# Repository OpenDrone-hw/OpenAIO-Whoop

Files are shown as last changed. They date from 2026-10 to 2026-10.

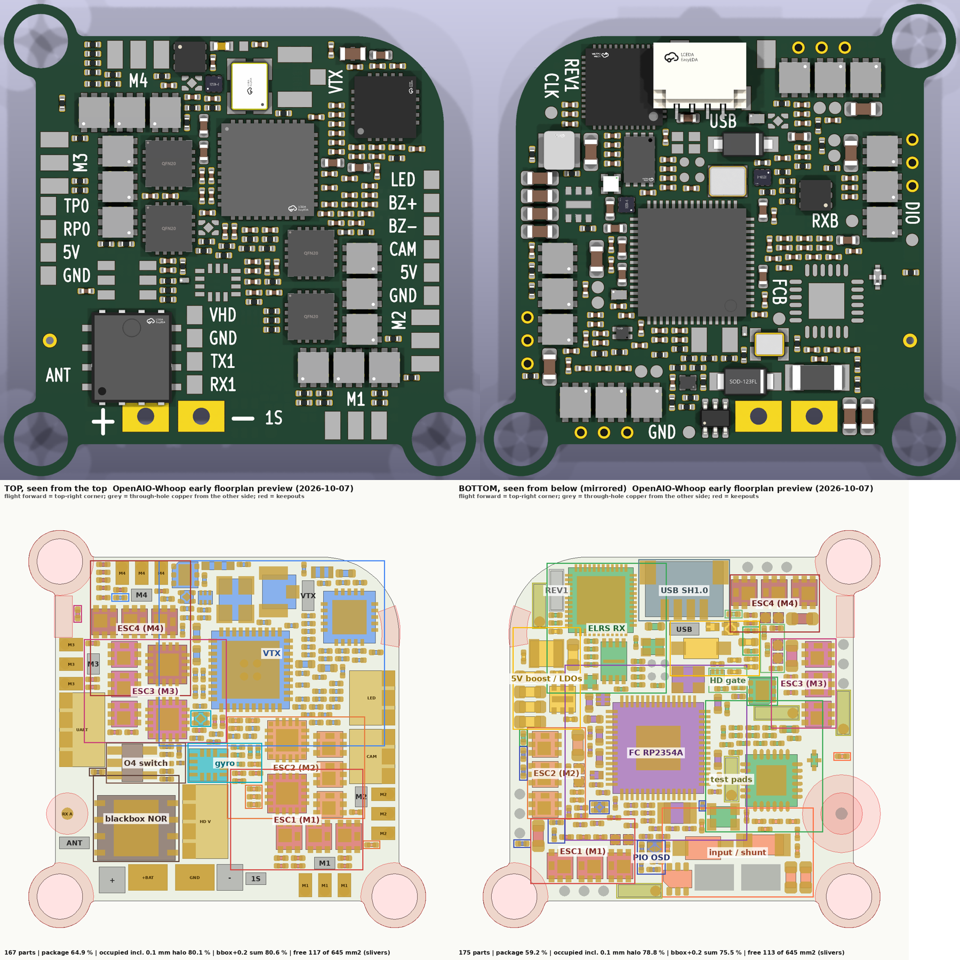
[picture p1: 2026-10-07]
images/floorplan-preview-overview.png

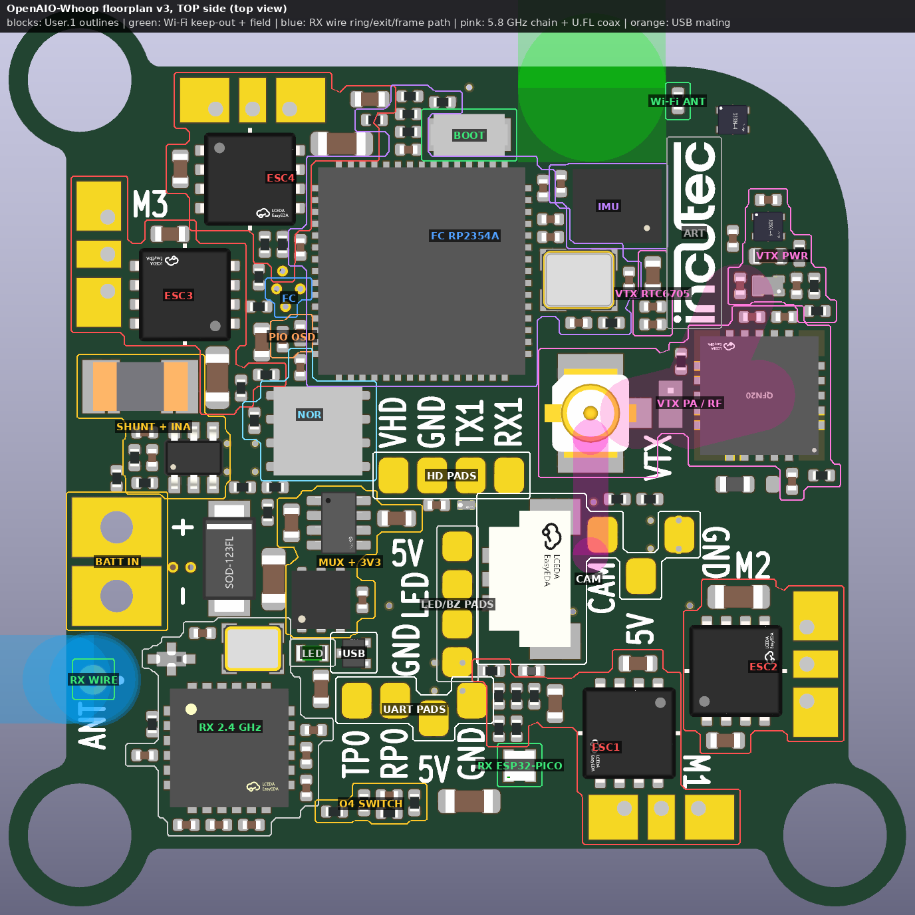
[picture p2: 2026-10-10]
images/floorplan-top.png

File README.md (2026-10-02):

# OpenAIO-Whoop

An all-in-one board for 1S whoops, 65 to 85 mm class: flight controller, four
brushless ESC channels, an ExpressLRS receiver and an onboard analog VTX on a
25.5 x 25.5 mm board. The 1S sibling of
[OpenAIO](https://github.com/OpenDrone-hw/OpenAIO), which covers 2S to 6S on
the same mounting pattern.




## Why

Whoops are where an AIO is not a convenience but the only option: there is no
room for a stack and no weight budget for connectors. 2S and up is OpenAIO's
range, so what is left for a second board is 1S, where the power tree starts
from a single cell and everything below +5V has to be boosted rather than
bucked. That is the whole design problem, and it is worth solving once.

Analog is the reason this board is separate rather than a variant. A 1S whoop
is the last class still flying analog in volume, and an onboard VTX is what
makes the board worth building instead of pointing people at a digital AIO
with an HD port.

## VTX dependency

RTC6705 is listed on LCSC (C913074) with no stock (checked 2026-10-02), so an
onboard analog VTX cannot be assembled from LCSC-sourced parts today; see
[OpenVTX](https://github.com/OpenDrone-hw/OpenVTX) for the same constraint. This board waits on that part becoming
orderable, or on a sourceable equivalent. Nothing else about it is hard, and
nothing has been drawn.

## Specifications

Targets. The board does not exist yet.

| | |
|---|---|
| Target class | 1S whoops, 65 to 85 mm |
| Mounting | 25.5 x 25.5 mm |
| Input | 1S LiPo |
| Flight controller | RP2354A class, Betaflight target |
| ESC | 4 channels |
| Receiver | ExpressLRS 2.4 GHz, serial |
| Video | Onboard analog VTX and OSD |
| Blackbox | SPI NOR flash |
| Assembly | Chosen per release. LCSC basic parts preferred |

## Constraints

- 25.5 x 25.5 mm mounting pattern, shared with OpenAIO.
- 1S only. 2S and above is OpenAIO, and covering both here would mean a wider
  front end for a range another board already serves.
- FC section reuses the [OpenFC-Lite-Mini](https://github.com/OpenDrone-hw/OpenFC-Lite-Mini) RP2354A design; Betaflight target derived from its target.
- Receiver is serial ELRS 2.4 GHz, reusing the [OpenRX Lite](https://github.com/OpenDrone-hw/OpenRX-Lite) design.
- Assembly from LCSC parts, basic parts preferred; assembly house chosen per
  release. Fab-ready manufacturing files are kept in a private Incutec production repository and are not published.

## Prior art

- [OpenFC-Lite-Mini](https://github.com/OpenDrone-hw/OpenFC-Lite-Mini) and [OpenRX Lite](https://github.com/OpenDrone-hw/OpenRX-Lite): the FC and RX stages this board reuses.
- [OpenAIO](https://github.com/OpenDrone-hw/OpenAIO): the 2-6S board, and the source of the ESC and power sheets that do not survive the drop to one cell.
- The class reference is the BetaFPV Matrix 1S 5IN1 II.
- An earlier stitched design was reset in August 2026 (see the git history before #9); reference for the thinking, not a design to continue from.

## Design questions

Open questions for the design:

- **VTX part.** Is there an RTC6705 equivalent in stock on LCSC, or a
  different route to 25 mW to 200 mW on the 5.8 GHz band that JLCPCB can place?
- **Power stage.** At 1S the pack is 3.0 to 4.35 V. Driven half-bridge needs a
  boosted gate rail; direct-drive P+N needs no driver but costs dead time,
  which AM32's `USE_INVERTED_HIGH` F421 targets run at 120-140 against 22-75
  for driver-based targets. Which one, and what does it do to the copper?
- **Electronics rail.** Everything from +5V down has to come from a boost or
  buck-boost off one cell, and it has to hold up with the cell sagging under
  full throttle. That is the part existing 1S-2S AIOs get wrong.
- **Motor connection.** Solder pads or connectors, given the class usually
  means replaceable motors.
- **Antenna.** Where the RX antenna and the VTX antenna go on a board this
  size with a duct around it, without desensitising the receiver.

## In the line

What pairs with what, and what is available:
[opendrone.be](https://opendrone.be).

## Contributing

See [CONTRIBUTING.md](CONTRIBUTING.md). KiCad files cannot be merged, so say
what you intend to change before you do, on
[Discord](https://discord.gg/v3sWmTcx3R).

## License

Hardware licensed under [CERN-OHL-S-2.0](https://ohwr.org/cern_ohl_s_v2.txt),
see [LICENSE](LICENSE).

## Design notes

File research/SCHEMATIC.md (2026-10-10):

# OpenAIO-Whoop schematic (P4 integration, 2026-10-09)

Status: the eleven sheet files written by the P4 shards are merged into one hierarchy and pass every scripted
check. P4 critique round 1 (4 MAJOR, 22 MINOR: 25 fixed, 1 rejected), round 2 (2 MAJOR, 19 MINOR: 19 fixed,
2 fixed in part, 0 rejected), round 3 (2 MAJOR, 17 MINOR: 17 fixed, 2 fixed in part, 0 rejected) and round 4
(7 MAJOR, 12 MINOR, two pairs of duplicates: 19 fixed, 0 rejected; section "P4 critique round 4") are applied;
the loop (D22: no BLOCKER / MAJOR left) continues with round 5. The board was **not** synced; round 4 changed
only its silkscreen again (the routing prep had promoted a checkpoint without the round-3 LED-row / M4 labels).
A scratch sync of the round-4 schematic gives schematic parity **0** (repo board: 25 until the next sync). The
P5 placement conditions are scripted (`hardware/tools/check_p5_conditions.py`, round 4 adds the RTC6705 C103
bypass and C94 / C95 crystal loads) and fail 31 of 46 on the current board (open item 10).

| Check | Result |
|---|---|
| `kicad-cli sch erc` (all severities) | **0 errors, 2 warnings** (both justified below); baseline before integration: 2 errors, 105 warnings |
| `hardware/tools/check_netlist.py` | **7 ok, 0 FAIL** (N1-N6, N5 run for the FC and the RX; N6 now also checks each net's class through the .kicad_pro patterns, D82) |
| `hardware/tools/check_conventions.py` | **39 ok, 0 FAIL**, 4 warn, 3 skip after round 4 (B7 requires each solder pad's nearest aligned silk label to equal its pad code; B8 / B9 pass on the board labels). Correction: round 3 reported 39 / 0, but the routing prep promoted `route/ckpt/28_candidate` over the board at 03:03:28, 6 s after the re-apply, so the repo board read **37 ok, 2 FAIL (B7, B9)** until round 4 re-applied the labels with `hardware/tools/silk_pad_labels.py` |
| `sch_visual_check.py` (commons, KiCad 10 hide fix: `p2v3/p4/rx/tools/svc_k10.py`, round 4 adds `textbox_intrusion`: a text or symbol body inside a note's rectangle, which caught C82's '+3V3' under the RX MCU note: 5 hits on the round-3 sheets) | **0 hits on all 11 sheets**; the unpatched commons copy counts the KiCad 10 hidden fields (9251 → 9353, not meaningful, ruling 2026-10-09); it has no frame-to-frame check, so round 2 added `frame_check.py` and round 3 (`p2v3/p4/fix3/scripts/frame_check.py`) gave it a title-block test: **0 title-block hits on all 11 sheets** (was 1: ESC half-bridge frame); its 19 other hits are house-style items present in the sibling sheets (OSD hand-drawn table grid, notes outside frames on RP2350A / ESC / PADS) |
| `hardware/tools/check_p5_conditions.py` (board placement conditions) | 15 ok, **31 FAIL** on the current board (round 3 added SMPS, BOOT, USB series R, NOR cap and LP5907 CIN conditions; round 4 adds C103 at RTC6705 pins 31/32 same side <= 1.0 mm (3.3 mm, F vs B), C94 / C95 at pins 24 / 25 <= 1.5 mm (2.0 / 4.5 mm)): P5 input, not a schematic error (open item 10) |
| `kicad-cli pcb drc --schematic-parity` | repo board **25** (21 footprint_filters_mismatch from the schematic, now fixed by project-lib copies, + 4 pending the C122 / D1 sync); after a scratch `sync_pcb.py` of the round-4 schematic **0** (ptest in `p2v3/p4/fix4`); the U20 NU / GND shorting_items error clears with that sync, the U5 WSON and C122 0402 lands then need 3 vias moved (FLOORPLAN open item 13) |
| `hardware/tools/check_footprint.py` R_0402_Selector_3Pad | PASS, 0 WARN (pad 3 paste-free by spec) |
| bom_plan parity (refs, values, footprints, symbols, MPN, Manufacturer, LCSC, DNP, BOM flag) | 274 of 274 symbols equal (check_netlist N4); LOGO1 is a board-only footprint |
| Netlist | 271 board parts (H1-H3 are schematic-only); 236 BOM placements, 82 BOM lines; 72 no-connect pins (U20 NU now on GND), 0 auto-named nets |
| Board silk (rounds 3 and 4) | kicad-cli DRC on the board: +1 silk_overlap warning (J33 GND label 0.148 mm from U6's tented EP via ring, accepted), no other change; round 4 re-applied the labels to the repo board and 21 route checkpoints / saves (`hardware/tools/silk_pad_labels.py`, `--check` = the promote gate) |

PDF: `hardware/OpenAIO-Whoop-schematic.pdf` (14 pages).

## Sheets

| Page | Sheet (file) | Paper | Refs | Reused from | Generator (scratchpad `p2v3/p4/`) |
|---|---|---|---|---|---|
| 1 | Root (`OpenAIO-Whoop.kicad_sch`) | A3 | - | OpenAIO root layout, signal flow left to right; power table | `hardware/tools/sch_root.py` from `sch_contract.json` |
| 2 | POWER (`power.kicad_sch`) | A3 | 38 | OpenFC-Lite-Mini power (LP5912 block), OpenAIO battery shunt + INA186; TPS61022, SGM40661, TPS2116, TPS22810 from TI/SGMICRO datasheets | `integrate/gens/power_sheet.py` |
| 3-6 | ESC1-ESC4 (`esc_channel.kicad_sch`, one file x4) | A4 | 17 x4 | OpenAIO esc_channel (BEMF network, C2 test points); EFM8BB51 + AGM210MAP stage new (D56) | `esc/build_esc.py` |
| 7 | RP2350A (`rp2350a.kicad_sch`) | A2 | 34 | OpenFC-Lite-Mini rp2350a (core, crystal, SMPS, USB series, VBAT divider, beeper FET) | `integrate/gens/build_rp2350a.py` |
| 8 | IMU (`imu.kicad_sch`) | A5 | 5 | OpenFC-Lite-Mini imu; commons blocks LDO_IMU_TPS7A2033 / IMU_ICM42688P_SPI | `imu/build_imu.py` |
| 9 | BLACKBOX (`blackbox.kicad_sch`) | A5 | 3 | OpenFC-Lite-Mini blackbox frame + SPI0 interface; PY25Q128HA NOR (D66) | `blackbox/build_blackbox.py` |
| 10 | OSD (`osd.kicad_sch`) | A4 | 12 | OpenFC-Lite-Mini osd (SN74LVC1G3157 + TLV7031 + SDM02U30), levels scaled (P4-10) | `osd/build_osd.py` |
| 11 | RX (`rx_esp32_sx1281.kicad_sch`) | A3 | 25 | OpenRX-Lite-UFL (SX1281 LDO mode, 52 MHz TCXO, Wi-Fi chip-antenna pi match, WS2812), ESP32-PICO-V3 DS Fig. 11 | `rx/build_rx.py` |
| 12 | VTX (`vtx.kicad_sch`) | A2 | 58 | OpenOSD-X v1.01 reference (video network, loop filter, PAOUT1 feed), Skyworks SE5004L EK1; no sibling sheet exists | `integrate/gens/gen_vtx.py` |
| 13 | LED (`led.kicad_sch`) | A5 | 4 | OpenFC-Lite-Mini rp2350a status-LED block (sink drive) | `integrate/gens/build_led.py` |
| 14 | PADS (`pads.kicad_sch`) | A3 | 27 | OpenFC-Lite-Mini pads (Conn_01x01 groups), OpenFC-Lite JST SH plug frame; camera plug, motor lands, ESD array new | `integrate/gens/build_pads.py` |

Naming (round 3): the sheet name **RP2350A**, its file `rp2350a.kicad_sch`, the net paths `/RP2350A/*` and the
bom_plan `sheet` field `rp2350a` (component class RP2350A) all follow the house OpenFC-Lite-Mini sheet (the RP2350
family name, as every other bom_plan sheet field follows its file); the part and the sheet title are RP2354A.

`integrate/gens/*` are the shard generators patched for the integration (`integrate/scripts/patch_gens.py` applies
the edits to the shard originals). After any generator run, `hardware/tools/sch_integrate.py` must run once.

## What the integration changed

- **Library pin types.** Twelve OpenDrone catalogue symbols typed every pin `unspecified`, which caused 105 ERC
  warnings and both errors (U13 SCLK and AE1 not driven). Per the ruling they are now project copies in
  `lib.kicad_sym` with datasheet pin types (list in research/LIBRARY.md); `bom_plan.json` `symbol` points at the
  copies. Pin-name cosmetics fixed on the copies: INA186, AP1606, SDM02U30, SDM02M30 (D8) names hidden, AOTA numbers
  hidden, BMI270 pins 2/3 lengthened so they reach the body.
- **PWR_FLAGs.** Regulator outputs are now `power_out` pins, so the flags on +3V3 (POWER) and +3V3_VTX (VTX) were
  removed (a flag next to a power output is an ERC error). Flags stay where the only source is passive or a
  connector: +BATT_IN, GND, +BATT, +5V_CAM, VBUS, +1V1, PA_VCC, plus a new one on VREG_AVDD (R41 RC filter, ERC asked).
  Contract rule 7 updated.
- **Rulings applied.** R84 10k -> 1k (RC0201FR-071KL; LP5912 EN 0.03-0.04 V with GPIO21 low). New **C134** 4.7 uF
  (CL05A475MP5NRNC, same line as C56) on +1V1 at DVDD pin 23. Net class pattern `*ADC_CURR*` -> Analog and `/VBUS` ->
  Power (setup_board.py NETCLASS_PATTERNS and .kicad_pro, same order). bom_plan net notes synced to the netlist for
  35 parts (U1 / C5 on SHUNT_SENSE_P_RC / N_RC, R64 on RTC_VT, R59 shunt, U22 from +3V3_VTX, O4_EN = U5_EN, ...).
  +3V3 Wi-Fi peak (0.48 A, bench-only mode) in the root power table.
- **Local labels on every multi-pin net** (contract rule 8): the 19 auto-named nets now carry labels named after the
  driving pin or the contract name: VTX RTC_CP / RTC_VT / RTC_LF, VT_MOD / VT_MOD_N1 / VT_MOD_N2, U19_XTAL1 / XTAL2,
  U19_REG1D8, U19_SPILE / SPICLK / SPIDATA, PA_RC1, Q27_B, Q27_E; RP2350A VREG_LX; POWER U5_CT; LED D5_K, D6_K.
- **Fields.** LCSC made consistent per MPN (GRM033C81E104KE14D = C181047, GRM155C80J106ME11D = C237279, sources in
  BOM-REDUCTION.md), so C12 / C15 and the other parts of those lines carry it.
- **Power-symbol references** numbered once over the hierarchy (#PWR01-#PWR247, #FLG01-#FLG08); the shards used
  colliding per-shard ranges.
- **Contract text** (sch_contract.json): J31 pinout (1 GND, 2 D-, 3 D+, 4 VBUS), USB block and PADS sheet source
  attribution, IMU pins 2/3/10/11 NC, R84, C134, VTX net names, PWR_FLAG rule, A9 decided, VBUS / ADC_CURR patterns.
- **A9 (LCSC) decided.** check_conventions A9 requires MPN + Manufacturer and an LCSC field; the LCSC value is
  required where the part has one (D60, NextPCB sources by MPN) and check_netlist N3 compares it to bom_plan. 63 BOM
  placements (25 lines) have no LCSC number. LINEUP-CONVENTIONS rule 9 carries the note.
- **Docs synced.** PINMAP §2/§3/§6 net columns use the schematic names (underscore buses, pin-side nets
  U10_USB_DM/DP, QSPI_SS, ADC_CURR, VTX_PWR_CTL, Wi-Fi AE2 row, GPIO0 button row) and list every ESP32 pin;
  DESIGN-SPEC R84 1 kOhm, IMU pins 2/3 NC, Wi-Fi paragraph marked superseded by D58. PADS sheet note follows D76
  (vertical BM04B), not the withdrawn D72 side-entry plug.
- **Tools.** New `hardware/tools/sch_integrate.py` (project-wide lib refresh, field sync, power references) and
  `hardware/tools/check_netlist.py`. `sch_build.py` no longer copies stock `property private` entries (kicad-cli
  refused those files); `sch_root.py` gives the power table a deterministic uuid.

## P4 critique round 1 (2026-10-09)

Single-writer fix pass `p2v3/p4/fix1` (scripts there; decisions D77-D80). Each item was checked against the
datasheet or file first.

| # | Sev | Item | Verdict | What changed |
|---|---|---|---|---|
| 1 | MAJOR | ESC commutation loop closed through planes (one shared 22 µF per ESC) | fixed (D77) | one 10 µF X6S 0402 GRM155C80J106ME11D per AGM210MAP, pin 3 S2 to pin 1 S1 at the lead side, via-in-pad: C20 / C23 / C21 per ESC (x4); 22 µF 0603 cell bulk out; ESC sheet note, bom_plan, DESIGN-SPEC §4.3 corrected |
| 2 | MAJOR | X1 ESR 150 Ω vs RP2350 Table 629 50 Ω | fixed (D78) | Abracon ABM8-272-T3 (C20625731, 3225 Dense land), C42 / C43 15 pF and R40 1k kept |
| 3 | MAJOR | FL1 TDK DEA 50 Ω LPF without the Semtech match / DC block | fixed (D80) | Johanson 2450FM07D0034T (house part, matched + DC blocked), lib:2450FM07D0034T + lib:FILTER-SMD_4P-L1.0-W0.5-L_W, IN at RFIO |
| 4 | MAJOR | R67 selector anchor on pad 2 (CPL centres the 0402 between lands) | fixed | footprint origin at the pad 1-2 midpoint, land spec updated, check_footprint PASS |
| 5 | MINOR | DESIGN-SPEC / PINMAP not synced to D56 / D57 | fixed | spec P4-status block, §1, §3, §4.1-4.3, §4.10, §15; PINMAP §7.1 / §7.3 |
| 6 | MINOR | root +5V row shows the HD figure of +5V_BST | fixed | +5V "0.70 A analog, about 0.25 A HD"; +5V_BST "0.70 A analog / 1.48 A HD (BEC 1.5 A cont.)" |
| 7 | MINOR | C30 redundant | fixed (D77) | deleted; ESC3's C35 carries BR-05 |
| 8 | MINOR | C17 adds little next to C8-C11 | fixed (D79) | deleted; P5 condition U5 VIN within 3 mm of C8-C11 / U3 VIN2 |
| 9 | MINOR | TPS61022 COUT ≥ 20 µF above 1.5 A not guaranteed | fixed (D79) | BEC published 1.5 A continuous; V1b 1.7 A step as characterisation |
| 10 | MINOR | PicoBlade 1.0 A contact rating | fixed | PADS note; README text owed (open item 8) |
| 11 | MINOR | J31 pin 1 inferred | fixed | V-plan gate V0-USB before the P5 freeze (spec §14), PADS note |
| 12 | MINOR | BR-05 3 mm vs 3.4-3.9 mm site | fixed | BR-05 amended to 4 mm through the +BATT plane (notes, bom_plan) |
| 13 | MINOR | U24 description quoted the page-1 surge claim | fixed | lib description: IN 28 V abs max, 2.7-20 V recommended |
| 14 | MINOR | Ralec 2.4k vs Yageo | **rejected** | RC0201FR-072K4L has no LCSC / JLC listing, 0 stock and 28 weeks at Future, obsolete at IC-Direct; the Ralec RTT012401FTH is a genuine standard part with stock |
| 15 | MINOR | L1 Manufacturer 'cjiang' | fixed | 'Changjiang Microelectronics (CJiang)' |
| 16 | MINOR | PINMAP RP0 SBUS text | fixed | PINMAP §2 pin 5 row and §5.1 comment (IO-SET row marked applied) |
| 17 | MINOR | boot / recovery sequence after D65 / D67 | fixed | spec §12.1, PINMAP F18, RX sheet button note |
| 18 | MINOR | PINMAP §7.1 / §7.3 still TI | fixed | AGM210MAP gate pins and routing; first power-up `A_X_10_96`, then `A_X_5_96` |
| 19 | MINOR | D0WD fallback and "no Wi-Fi" text | fixed | spec and PINMAP marked withdrawn (D55 / D61), F9 per D58 |
| 20 | MINOR | stale texts (PINMAP status, W25Q128JV, R84 10k, '4.7k') | fixed | all four |
| 21 | MINOR | OSD level note assumed no DC load | fixed | recomputed: 1.47 kΩ DC load, black 0.234-0.236 V, white 0.920-0.927 V; V9b check (the HF load / edge figures were corrected in round 2, item 18) |
| 22 | MINOR | VTX analog nets in Default | fixed | Analog patterns `*/VT_MOD*`, `*/RTC_*`, `*/U19_XTAL*`, `*/TCXO_OUT`, `*/XTA` (setup_board.py, .kicad_pro, check_netlist N6; the In2 / In3 Analog DRU rule covers them) |
| 23 | MINOR | LP5907 abs max and VREF window margins | fixed | deviations recorded in the PA REFERENCE note; V5c / V9b |
| 24 | MINOR | R84, R80-R82 position, SE5004L "match" | fixed | notes (R84 1k, R80-R82 at the ESP32 end), spec §4.8 |
| 25 | MINOR | VTX / RX sheet style | fixed | framed blocks with titles, notes inside each frame, Q27_C -> R65 one wire (drive stage beside the PAOUT1 feed), net `PA_BIAS_PWM` -> `VTX_AMP_PWM` |
| 26 | MINOR | +3V3_VTX budget 0.10 A | fixed | root table "0.10 A typ, about 0.17 A at max PA", spec §5.1 |

Placements 269 -> 275 in bom_plan (+8 hot-loop caps, -C30, -C17), 82 lines unchanged.

## P4 critique round 2 (2026-10-10)

Single-writer fix pass `p2v3/p4/fix2` (scripts there; decisions D81-D82). Each item was checked against the
datasheet, the source code or the board first. No part added or removed: 275 placements, 236 BOM, 82 lines.

| # | Sev | Item | Verdict | What changed |
|---|---|---|---|---|
| 1 | MAJOR | ELRS `vtx_miso` 'unset' keeps the stock 23 (PICO flash DI) under an overlay | fixed (D81) | verified: `UnifiedConfiguration.py` `hardware.update(overlay)`, `hardware.cpp` absent key → -1, arduino-esp32 2.0.17 `spiAttachMISO` → `pinMode(miso, INPUT)` (-1 → HSPI GPIO12, NC here); `"vtx_miso": -1` written explicitly in the RX note, PINMAP §6 / F8 / row 25, spec §4.7 / §12 / P4-6, contract; V9 bring-up check |
| 2 | MAJOR | PA_VCC Power only by directive label: Default on the board | fixed (D82) | verified on the netlist vs the patterns (only PA_VCC differed); `/VTX/PA_VCC` → Power in setup_board.py and .kicad_pro; contract text; check_netlist N6 resolves every net through the .kicad_pro patterns (tested: fails on the old .kicad_pro) |
| 3 | MINOR | P5 placement conditions not met on floorplan v3 | fixed in part | new `tools/check_p5_conditions.py` (D77, BR-05, D79, BR-14 with the LP5912 1 cm rule of DS 9.2.2.2, BR-08, C108, R80-R82, USB inlet, boost COUT): 12 ok / 20 FAIL; bom_plan BR-05 claim corrected (2.6-5.0 mm), U5 / U21 fallbacks named (1 µF 0201 / 10 µF 0402). Moving parts is the board stage's (no board change in this pass) |
| 4 | MINOR | R67 pad 3 carries paste (+5V bridge risk) | fixed | F.Paste removed from pad 3; land spec `no_paste`; check_footprint `no_paste` key (additive); spec §4.2 row |
| 5 | MINOR | U2_SW in Default | fixed (D82) | `/POWER/U2_SW` → Phase (0.50 mm; short U2 SW-L1 pour) pattern + directive label on POWER; N6 rule; spec net-class table |
| 6 | MINOR | TPS61022 4.8 V start-up limit (VOUT pre-bias < 0.7 V) missing | fixed | verified SLVSDX7D §6.3; POWER battery note, spec §4.1 hot-plug row, V3c pass criterion |
| 7 | MINOR | R73 / R65 34 mW at the top step vs RC0201 derating | fixed | verified (RC0201 −55..125 °C, 36 mW at 85 °C); V8 pass criterion, levers (ELRS top-count cap Ic ≤ 45 mA, Re 27R); VTX note, bom_plan; R73 stays 10R (ruling 2026-10-09) |
| 8 | MINOR | 'Cout < 40 µF' ignores C12/C13 and the O4 input | fixed | verified TI §8.2.2.4 (C3 ≈ 1.7 nF with 47k); POWER note restated; V1b steps the load in HD mode with a real O4; FF cap only if it rings |
| 9 | MINOR | stale texts | fixed | spec C17 (D79) and ESC MCU supply (D77) rows; SGM40661 description 3 A continuous / 4 A abs max; bom_plan U2 / C16 / U6-U9 notes. D1 note: TPS2116 **kept** with its path named (the TPS61022 pass-through carries a cell surge to +5V_BST = VIN2, spec §4.1 / §4.2) |
| 10 | MINOR | blackbox reads at 75 MHz, not 50 | fixed | verified (`spiCalculateDivider` even prescale ≥ 2; {133, 80} → 75 MHz; tCLQV 6-7 ns); BLACKBOX note, spec §4.9 / §10, PINMAP F7, V9 read-back CRC gate, fallback |
| 11 | MINOR | IO-SET predates D65/D67/D69/D76 | fixed | status block at the top (button, motor plugs, test vias, D69, final refs J31 / J32 / J33) |
| 12 | MINOR | RX1 5 V-logic device at power-up | fixed | RP2350A P4-11 and PADS HD notes; README item (open item 8) |
| 13 | MINOR | R44 / U16 / J32 notes, V-btn 'pressed' | fixed | RPi guide R6 = 1k; H1/H3 wording dropped (D69); Wi-Fi peak ruling cited; V-btn 'while released' |
| 14 | MINOR | check_netlist table stale | fixed | table below from the current run |
| 15 | MINOR | root POWER block lists 'ESC3 BULK' | fixed | contract content, root regenerated |
| 16 | MINOR | RX frames overlap; notes outside frames | fixed | SX1281 frame right edge 203.2; NOTES band on top, BOOT / BIND and ESP32 frames span the right column with their notes inside |
| 17 | MINOR | VTX sheet sparse (A2) | fixed in part | RTC6705 and PA blocks moved up 30.48 mm (band under the frame title closed); A2 kept: the four block columns need about 567 mm of width, an A3 re-flow means redrawing the RTC6705 and PA blocks |
| 18 | MINOR | VIDEO_OUT HF load / edge figures | fixed | 0.95 kΩ at 5 MHz, 0.60 kΩ at 10 MHz; OSD edges x0.86 / x0.80, camera x0.97 (OSD and VTX notes, spec V9b, round-1 #21 row) |
| 19 | MINOR | PNP numbers disagree (spec / PINMAP vs ngspice) | fixed | spec §4.8 and PINMAP §6 from the ngspice table (copied to `research/bomred/verify/pnp_spice/`); Q27 ≤ 114 mW vs 130 mW at 85 °C; Q27 case temperature in V5 |
| 20 | MINOR | X4 250 Ω ESR, start-up margin untested | fixed | verified (LCSC C400090); V5 start-up margin test, lower-ESR 3225 fallback (bom_plan, VTX bench note) |
| 21 | MINOR | AE1 value 'ANT 2.4G wire' ≠ pad code | fixed | value `ANT` (bom_plan + schematic); wording in the notes |

## P4 critique round 4 (2026-10-10)

Single-writer fix pass `p2v3/p4/fix4` (scripts there). Each item was checked against the datasheet, the source or the
board first. No part added or removed (275 placements, 236 BOM, 82 lines); one package change (U5 DBV → DRV, D83), one
value change (R68 100k → 47k, existing 47k line); five project-lib symbols (TPS22810DRVR, D_BAS16LD, L_FTC252012,
R_Shunt_Kelvin, SolderPad_01x01). Decisions D83 (U5 package) and D84 (PicoBlade ring DRU exception, D21 log).

| # | Sev | Item | Verdict | What changed |
|---|---|---|---|---|
| 1 | MAJOR | U5 TPS22810DBVR kept only for stock (smallest-package rule, D60) | fixed | verified SLVSDH0C §6 (DRV pins 1 VOUT 2 QOD 3 CT 4 GND 5 EN/UVLO 6 VIN), §7.3 (3 A vs 2 A at TA 65 °C), §7.4 (RθJA 74.6 vs 182 K/W), orderable table (DRVR Active); thermal pad: TI's TPS22810EVM ties U2 TPS22810DRV PAD 7 to GND 4 (SLVUAY7B Fig. 1), so EP 7 goes to GND; new `lib:TPS22810DRVR` (taller body, GND / EP names clear EN/UVLO, closes the open item 11 overlap for U5) on the LP5912 WSON land; bom_plan one line (no LCSC number), POWER note, spec §4.2 / §9 / §10 / §15.3 / §16, D83. Board: swap at the next sync; a scratch sync puts pad 5 on a GND via and EP 7 on a +BATT via of the prep (FLOORPLAN open item 13) |
| 2 + 7 | MAJOR | LED-row / M4 silk lost again (repo board = route ckpt/28_candidate, B7 + B9 FAIL) | fixed | verified (md5 = 28_candidate, check_conventions 37 / 2 FAIL); `silk_fix3.py` moved into the repo as `hardware/tools/silk_pad_labels.py` (same table: pad Values, M4 at J13; `--check` exits 1 when a label is missing or off its pad) and applied to the repo board and to every route checkpoint / save older than two minutes (21 files: ckpt/28_candidate, 29, v1sp_00 … 14, v2of_00 … 02, v2-outer-first/save/*, v1-short-passes/save/00_repo), all `--check` OK; check_conventions 39 ok / 0 FAIL; DRC +1 silk_overlap (as round 3). Making it stick: setup_board.py owns rules and outline, not pad labels (they came from the floorplan build's silk step), so the gate is the promote step: run `silk_pad_labels.py BOARD` + check_conventions (B7 / B9 ok) before any copy to the repo (tool docstring, FLOORPLAN open item 6 reopened until the routing stage does it); round-3 counts corrected above |
| 3 | MAJOR | spec §4.7 / §9 / §11 present the withdrawn BR-01 gate, D0WD fallback, LNA_IN dummy load and H1-H3 | fixed | §4.7 decision line 'D55: not gated, no fallback', Gate / Fallback paragraph → 'Superseded (D55, D61, D69)', the 'same JSON serves the fallback' sentence, RX MCU / flash / 40 MHz fallback cells 'withdrawn (D55, D61), never to be used', LNA_IN = AE2 behind R88 (D58) in §4.7 and §9, §11 H1-H3 void (D69, N1 and gyro distances as preferences), §11 crystal line; also the live H1 mentions in §4.3 and §10 |
| 4 + 13 | MAJOR / MINOR | spec §4.10 / §13 describe the pre-D64 / D65 IO set | fixed | Motors (PicoBlade lands J4 / J7 / J10 / J13, DNP 53047-0310, D84 ring exception), Camera (J32 SUR plug + J23-J25 in front), User / HD pads (15 pads, GND LED 5V BZ- with J33, D70 0.2 mm halo), battery vias 0.35 / 0.20 (spec and bom_plan J2 / J3), §13 silk codes = bom_plan pad codes; D84 logs the 0.35 mm PicoBlade-ring DRU exception (it was only a DRU comment) and §15.3 lists it as an EQ item |
| 5 | MAJOR | U20 SE5004L pin 1 NU no-connect inside the GND land (only DRC error) | fixed | verified footprint (pad 1 at (-1.85, -1) inside the pad 21 frame) and DS 202393B (pin 1 open in the package); gen_vtx: stub + GND pointing down, PA note 'NU (open in the package) tied to GND: it lies in the DS ground metal', contract note; scratch sync: the shorting_items error is gone |
| 6 | MAJOR | 21 footprint_filters_mismatch parity issues from the schematic | fixed | verified the filters; D7 filter `*SOT*9X3*DRT*`; project copies `lib:D_BAS16LD` (`*SOD882*`), `lib:L_FTC252012` (`IND-SMD*`), `lib:R_Shunt_Kelvin` (`R_*Kelvin*`), `lib:SolderPad_01x01` (`SolderPad_* BattPad_*`, Conn_01x01 graphics) for J2 / J3 / J16-J29 / J33; check_conventions A16 / B7 use the footprint, so they accept it; LINEUP rule 16 names the copy; scratch sync parity 0 |
| 8 | MINOR | EFM8BB51 RAMPVDD ≥ 10 µs/V not recorded | fixed | verified DS Table 4.7; ESC VDD note and spec §4.4 record it as a Matrix-parity deviation (hot plug about 1 µs/V; the 2.2-4.7 Ω VDD R gives τ 0.5 µs, a real fix needs ≥ 15 µs); V3c: 20 hot plugs, all ESCs answer DShot / EDT, settings intact, no stuck reset |
| 9 | MINOR | VTX LDO enable margin checked at 25 °C only | fixed | verified AP1606 IDSS ≤ 1 / 100 µA at 25 / 125 °C (about 16 µA at 85 °C), VGS(th) 0.4-1.2 V at 250 µA, LP5912 VEN(ON) ≤ 1.3 V, VEN(OFF) ≥ 0.3 V, 3 MΩ pull-down; R68 → 47k (RC0201FR-0747KL, existing line): 42 µA leakage margin (was 20), GPIO21 low 0.07 V, Q28 sinks 70 µA; VTX and P4-11 notes with the hot figures, contract, V9 hot-soak boot at 85 °C |
| 10 | MINOR | TPS2116 §7.3.4 RCB recommendation not dispositioned | fixed | verified §7.3.4; mux note and spec §4.2 cite it as a considered deviation (no part); V1: VIN1 / VOUT ≤ 6.0 V and +3V3 ≥ 3.0 V on every plug and unplug |
| 11 | MINOR | SMF5.0A VBR 6.40-7.07 V; lib Datasheet empty | fixed | verified Littelfuse SMF table (6.40-7.00 V at 10 mA, IR ≤ 400 µA, VC 9.2 V at 21.7 A); POWER note, spec §4.1, lib description; Datasheet = the LCSC mirror of the Littelfuse SMF datasheet (C151296 = D1) |
| 12 | MINOR | spec §4.2 / §4.4 stale power text | fixed | H2 as a D69 preference, Wi-Fi 0.48 A bench peak, PR1 3.44-4.04 V (3.37-4.10 V 1 %), no C30 / X6S-distance clause, C17 deleted (D79), +3V3_VTX 16.0 / 6.8 µF, no gate R / 0R options |
| 14 | MINOR | PADS motor-land note gives B for J7 / J13 | fixed | verified bom_plan and board (all four F); note rewritten |
| 15 | MINOR | PINMAP §4.5 pull-down 35-189 kΩ (1.8 V row) | fixed | verified RP2350 DS (36-113 kΩ at IOVDD 3.3 V) |
| 16 | MINOR | RX MCU note printed over C82 '+3V3' | fixed | measured on the round-3 PDF (note ink to y 164.3, svc model 160.3); C76 / C82 moved below the note (y 186.69, right of the hierarchical labels); svc_k10 `textbox_intrusion` added (5 hits on the round-3 sheet, 0 now) |
| 17 | MINOR | C103 / C94 / C95 placement not checked | fixed (P5 input) | verified pins (C103 on +3V3_VTX at pins 31/32, C94 / C95 on XTAL1 / XTAL2 pins 24 / 25); `check_p5_conditions.py` VTX: C103 same side <= 1.0 mm, C94 / C95 <= 1.5 mm (all FAIL now: 3.3 mm F vs B, 2.0, 4.5 mm); move at the next placement pass (FLOORPLAN open item 13) |
| 18 | MINOR | FL1 still called 'LPF'; Wi-Fi '<= 8 mm' as a requirement | fixed | root block 'FILTER + WIRE ANT', contract block name / source, spec §2 / §10 rows; RX Wi-Fi note '<= 8 mm preferred, D69; FLOORPLAN open item 10'. bom_plan region key `radio_lpf` left as is (floorplan-owned field) |
| 19 | MINOR | IO-SET row 12 still lists TP10 / TP11 pads | fixed | row 12 = D67 set (TP1-TP8, TP9, TP12, TP13 as mask-open filled vias, no silk; TP10 / TP11 removed) |

## P4 critique round 3 (2026-10-10)

Single-writer fix pass `p2v3/p4/fix3` (scripts there). Each item was checked against the datasheet, the source or the
board first. No part added or removed (275 placements, 236 BOM, 82 lines); one value / package change (C122).

| # | Sev | Item | Verdict | What changed |
|---|---|---|---|---|
| 1 | MAJOR | RP2354A SMPS CIN / LX / COUT on the far side (U10 F, C58 / L2 / C56 / C57 B) | fixed in part | verified RP2350 DS 6.3.8.1 ("Don't place any of CIN/LX/COUT on the opposite side"); `check_p5_conditions.py` SMPS (C58 / L2 LX pad / C56 / C57 on U10's side within 3 mm of pins 49 / 48 / 50 / 46, L2 pad nets); FLOORPLAN open item 11 (move them to F with SW1 / D8, routing conditions, deviation + V9 fallback); sheet note DS Fig. 26 / 28 + P5 reference; bom_plan notes. Moving the parts is the placement stage's |
| 2 | MAJOR | LED-row silk labels one pad off (BZ- pad read '5V'), no M4; B7 blind to it | fixed | verified on the board; labels re-placed one per pad (BZ- 5V LED GND, aligned) and M4 at J13 (`silk_fix3.py`, idempotent); check_conventions B7 = nearest aligned label must equal the pad code (fails on the old board: J20 / J21 / J22); 39 ok, 0 FAIL |
| 3 | MINOR | LP5907 CIN below 0.7 µF effective | fixed (option a) | verified SNVS798Q 5.6 / 7.2.2.4; C122 → Samsung CL05A475MP5NRNC 4.7 µF 0402 (existing line, about 2.6 µF at 3.3 V); +3V3_VTX 16.0 µF nominal / about 6.8 µF effective, inside the LP5912 10 µF; VTX notes, spec §4.2 row and P4-17, P5 condition (same side, ≤ 1.5 mm) |
| 4 | MINOR | spec power-esc passages describe the TI stage / old decisions | fixed | verified AGM210MAP DS VER2.73 Table 1 (VDS 20 / −20 V, VGS ±12 V, EAS 36 / 49 mJ); spec §4.1 TVS row and §15.4 row (TI text kept as fallback), §4.4 bulk (D77), §5.3 H2 as a D69 preference with V1, 10 µF 0402 at about 2.6-2.8 µF at 4.2 V (spec table and ESC VDD note) |
| 5 | MINOR | §15.3 predates D56-D66; PY25Q128HA quote risk only in LIBRARY.md | fixed | §15.3 regenerated from bom_plan under D60 as a per-line quote check (stall-risk lines first); open item 12; bom_plan U13 note |
| 6 | MINOR | O4 enable thresholds stated three ways | fixed | verified TPS22810 VENR 1.13-1.30 / VENF 1.08-1.18 V with 33k / 18k / 510k and +5V_HD 4.93-5.37 V: on 3.23-3.82 V, shed 2.74-3.14 V (1 %); PADS note, spec §1 / §4.2 / §5.3 / V1 / §15.4 / P4-1, PINMAP F21 |
| 7 | MINOR | ESC half-bridge frame enters the A4 title block | fixed | frame right edge 177.8 → 175.26, stage note narrowed; frame_check title-block test, 0 hits on 11 sheets |
| 8 | MINOR | D1 SMF5.0A drawn as a zener | fixed | project-lib `lib:SMF5.0A` (unidirectional TVS bar, pins 1 K / 2 A as before; filter `SOD?123F*` also clears D1's footprint_filters_mismatch); the stock Device:D_TVS is bidirectional (A1 / A2), so not used |
| 9 | MINOR | R44 / D8 / R43 / C65 placement conditions unscripted | fixed in part | `check_p5_conditions.py` BOOT / USB / NOR (all FAIL on the current board); FLOORPLAN open item 12; bom_plan notes. Moves are the placement stage's |
| 10 | MINOR | CS ≥ 2.75 V at reset overstated | fixed | verified RPD 36-113 kΩ at 3.3 V (DS Table 1683): ≥ 2.58 V (0.78 VDD) > 2.31 V; PINMAP §4.5, IMU note |
| 11 | MINOR | spec §4.5 / §4.9 / §10 / P4-6 / §2 describe earlier variants | fixed | D78 crystal row, D57 / D76 USB, SW1 + D8 + R44 boot, D66 NOR table and paragraph, §10 test-via (and USB) rows, P4-6 RX_BOOT |
| 12 | MINOR | PINMAP §5.4 lacks the IO-SET §2.3 presets | fixed | EXT-HD-PADS, EXT-USER-PADS, I2C-USER, I2C-HD rows (resource moves, pull-ups, passthrough, V9); IO-SET §2.2 item marked applied |
| 13 | MINOR | GPIO5 strap reads 0 in HD mode | fixed | RX note: 1 with +3V3_VTX up, 0 in HD mode (RTC6705 unpowered), SDIO-slave timing only |
| 14 | MINOR | GPIO13 'floating' at reset: three numbers | fixed | verified ESP32 DS IO_MUX (MTCK after reset oe=0, ie=1, wpd) and ngspice case 4 (10.2-18.9 mA at Re 10 Ω); VTX note, spec §4.8 start-up and ExpressLRS row (patch (4) GPIO13 part dropped: stock ELRS sets the pit count at init), PINMAP §6 row and F15; V5 download-mode leakage |
| 15 | MINOR | RX_LED label touches VTX_PWR_CTL | fixed | IO22 routed one grid lower; svc_k10 0 hits |
| 16 | MINOR | net-class colours swapped against OpenAIO, RF near wire green | fixed | OpenAIO colours (Phase magenta, Power orange, RF gold, Analog teal, VBAT red, USB blue), Gate violet rgb(120, 60, 220) (OpenAIO's green sits on the wire colour), GND grey; `setup_board.py` + .kicad_pro; PDF re-exported |
| 17 | MINOR | root power table lacks PA_VREF | fixed | contract row (U22 LP5907-2.85, EN = PA_EN, off in HD, 2.85 V, about 10 mA = SE5004L IEN typ, whose DS condition already includes the 2 kΩ pull-down), root regenerated |
| 18 | MINOR | sheet named RP2350A vs bom_plan 'rp2354a' | fixed (option b) | bom_plan `sheet` = `rp2350a` (sheet name / file stem, house name; component class RP2350A); no net path renames on the board; naming line in "Sheets" |
| 19 | MINOR | spec §2 temperature table / bom_plan rx lib_items stale | fixed | PY25Q128HA (D66), ABM8-272-T3 (D78), 2450FM07D0034T (D80), JST plugs added, BR-01 fallbacks dropped (D55 / D61), H1 condition removed (D69); rx lib_items → `lib:FILTER-SMD_4P-L1.0-W0.5-L_W` + `lib:2450FM07D0034T` |

## ERC: the two remaining warnings

| Sheet | Warning | Why it stays |
|---|---|---|
| BLACKBOX | U13 pin 3 WP#/IO2 (bidirectional) on +3V3, driven by U4 OUT (power output) | Deliberate tie: WP# high disables write protection; Betaflight drives the NOR in 1-bit SPI only and the status/config registers ship as 00h, so IO2 never drives. KiCad flags every bidirectional pin on a power rail. |
| BLACKBOX | U13 pin 7 HOLD#/RESET#/IO3 (bidirectional) on +3V3, same | PY25Q128HA: HOLD#/RESET# must not float; tied high as on the house blackbox sheet. Same reasoning. |

No ERC exclusions and no severity changes are used (D7 / D21).

## check_netlist.py

| Id | Check | Result |
|---|---|---|
| N1 | single-pin nets only on no-connect pins or test points | 73 single-pin nets, all on flagged no-connect pins |
| N2 | every supply input shares its net with a capacitor to GND | 59 power-input pins on 13 supply nets, all decoupled |
| N3 | footprint on every part; MPN + Manufacturer + LCSC field on BOM parts, LCSC = bom_plan | 274 symbols, 236 BOM placements ok (63 without an LCSC number, D60) |
| N4 | refs, values, footprints, symbols, MPN, Manufacturer, DNP, BOM flag = bom_plan.json | 274 equal; LOGO1 board-only; H1-H3 not on the board (outline holes) |
| N5 | U10 RP2354A and U16 ESP32-PICO-V3 pin -> net = PINMAP.md §2/§3/§6 | 61 + 49 pins equal |
| N6 | net classes from patterns + directive labels match each net's role; contract directive labels present; each net's .kicad_pro pattern class = its netlist class (D82) | Analog 25, Gate 24, Phase 13, Power 11, RF 8, USB 2, VBAT 2, GND 1, Default 104; 20 / 20 directive labels; 0 pattern mismatches |

## check_conventions.py warnings and skips

A5 deprecated wordmark gold (the lineup decision is to copy the shipped artwork exactly); A11b `+1V1 +1V8 +3V3
+3V3_VTX +BATT_IN` (LINEUP A11 names chosen for this board); B12 silkscreen font (board stage);
D1 README section "VTX dependency" (README). Skips: C3 and B18 (alpha stage), B17b (no model-fixes file).

## Closed deferred items

- POWER: U1 net names synced to bom_plan; O4_EN / PR1 aliases recorded as U5_EN / U3_PR1; C12 / C15 LCSC; R7 note;
  #PWR numbering; INA186 pin names; unspecified pins; P4-1/2/3/7/9/12/17/19 drawn with the accepted rulings.
- VTX: R84 1k; bom_plan nets for R64 / R59 / R60 / U22 / R65 / Q27; +3V3_VTX flag removed, PA_VCC flag kept; sch_build
  `private` bug fixed in the tool; PNP drive SPICE passed (P4-5); P4-18 (C119 deleted) noted on the sheet.
- RX: FL1 / X3 / D4 pin types (AE1 error gone); PA_NTC error gone with the VTX sheet present; D8 pin names; Wi-Fi peak
  in the power table; PINMAP LNA_IN and GPIO0 rows; D4 stays on +3V3 (ruling, bench V-LED).
- OSD: library pin types and the SDM02U30 names; cross-sheet items gone.
- RP2350A: ADC_CURR pattern; C134 fitted; +1V1 flag kept, VREG_AVDD flag added; AP1606 / AOTA cosmetics; TP9 / TP12 /
  TP13 bom_plan sheet = rp2354a.
- PADS: contract J31 pinout and source text; J31 note per D76; H1-H3 notes on the D73 25.5 mm square; VBUS flag.
- ESC: 4-instance netlist clean in the merged project (the standalone +BATT / GND errors came from the missing POWER).
- BLACKBOX: U13 SCLK now driven (typed RP2354A GPIO); WP / HOLD warnings justified above.
- IMU: pins 2/3 NC propagated to contract, bom_plan and DESIGN-SPEC; BMI270 pin types and pin length.
- All: A9 decided; #PWR collisions; commons sch_visual_check run with the KiCad 10 hide fix (the ruling's patched copy).

## Open items

1. **P4 critique loop** (D22): rounds 1-4 applied; round 5 to run.
2. **Board sync (after floorplan v3):** `sync_pcb.py` will add C134 (needs a site at RP2354A DVDD pin 23), drop the GND
   net from BMI270 pads 2/3, rename 19 nets (new labels), change R84's value, and must not expect H1-H3 (no board
   footprint). bom_plan.json changed (C134, symbols, R84, LCSC, nets): a floorplan run that rewrites bom_plan must merge.
   Round 1 adds: new C20/C21, C26/C27, C32/C33, C38/C39 (0402 at each AGM210MAP's lead side, pin 3 to pin 1);
   C23/C29/C35/C41 0603 -> 0402; C17 and C30 removed; X1 -> 3225 Dense land (+3 mm²); FL1 -> FILTER-SMD_4P-L1.0-W0.5-L_W
   (same pad set); R67's pads move 0.425 mm against its origin (new anchor); net PA_BIAS_PWM -> VTX_AMP_PWM; 10 more
   Analog nets.
3. **DRU net patterns** (routing stage): `*SPI0.*`, `*SPI1.*`, `*VTX_SPI.*` in OpenAIO-Whoop.kicad_dru /
   setup_board.py match no net (the nets are `SPI0_*`, `SPI1_*`, `VTX_SPI_*`): the 3 mm antenna keep-out and the
   In2/In3 sensitive-net rule miss them. Use `*SPI0_*`, `*SPI1_*`, `*VTX_SPI_*` and re-apply.
4. **R54 PS-O1** (OSD proposal: 287R -> 270R RC0201FR-07270RL, -1 BOM line, levels still inside P4-10): orchestrator decision.
5. **Camera gate G1** (J32 pitch and pin 1) and **J31 pin 1 = GND**: gate V0-USB before the P5 freeze (spec §14).
6. **ESC dead time:** closed in round 1 (first power-up `A_X_10_96`, `A_X_5_96` after V2; spec §4.3 / §12, PINMAP §7.3).
7. **ICM-42688-P** VDD 1.8 V with VDDIO 3.3 V: confirm in TDK DS-000347 before the TDK half of the V10 fly-off.
8. **README notes owed** (rulings): ELRS Wi-Fi is a bench-only mode (+3V3 0.48 A peak); SGM40661 OVP 5.75-6.12 V
   (out-of-spec sources only); no user UART pads since D89 (TP0/RP0 removed), so TX1/RX1 are the one free UART (hardware UART1, analog builds) and take 3.3 V logic only (5V pads come up before +3V3; FT pads take 3.63 V unpowered); 5 V BEC 1.5 A continuous and
   the LED-strip limit in HD mode (D79); the optional PicoBlade motor plug carries Molex's 1.0 A contact rating, the
   published ESC ratings apply to soldered motor wires, plugged motors at the user's risk; the boot / ELRS recovery
   sequence (hold SW1 at power-up, write the UF2, esptool through passthrough; spec §12.1).
9. **Bench checks** carried by the sheet notes: V1 (+5V unplug dip, O4 EN thresholds), V5/V8 (R73 final value,
   RTC6705 pin 11 spur), V9 (MOTOR pads before +3V3, HD back-feed), V-LED (D4 on 3.3 V).
10. **Placement conditions for P5**, scripted in `hardware/tools/check_p5_conditions.py` (run it on the board;
    current board 15 ok, 31 FAIL; round 4 added C103 (pins 31/32, same side, <= 1.0 mm) and C94 / C95 (pins 24 / 25,
    <= 1.5 mm); round 3 added: RP2354A SMPS C58 / L2 / C56 / C57 on U10's side within 3 mm of pins
    49 / 48 / 50 / 46 (RP2350 DS 6.3.8.1, now all on B), R44 at pin 60 (7.4 mm, B), D8 on SW1's side (B vs F), R43 at
    pin 51 (2.3 mm), C65 at U13 pin 8 (2.1 mm), C122 at U22 IN (ok); FLOORPLAN open items 11 / 12. Round 2 list,
    floorplan v3: 12 ok, 20 FAIL: 9 of 12 hot-loop caps off their AGM210MAP's side or > 1.5 mm from pins 1-3;
    BR-05 ESC1 / ESC2 bulk 5.0 / 4.7 mm and C19 / C31 100 nF > 1.2 mm; U5 VIN 6.1 mm from C8-C11 (> 3 mm);
    U21 IN 14.8 mm from C13 (> 1 cm, LP5912 DS 9.2.2.2); C108 2.7 mm from RTC6705 pins 39/40; R81 at the
    RTC6705 end; U24 12.5 mm and D7 5.9 mm (other side) from J31; boost C10 / C11 5.3 / 7.2 mm from VOUT).
    Fallbacks if P5 cannot meet U5 / U21: a 1 µF 0201 (GRM033R61A105ME44D) at U5 VIN, a 10 µF 0402
    (GRM155C80J106ME11D) at U21 IN (decision). The conditions (sheet notes): each ESC hot-loop cap across its AGM210MAP pins 3/1 at the lead side
    with via-in-pad (D77); BR-05 (amended) phase-B cap within 4 mm of EFM8 VDD through the +BATT plane; U5 VIN within
    3 mm of C8-C11 / U3 VIN2 (D79); BR-14 C13 between the U4 and U21 IN pins, BR-08 C49 / C54 at pins 44 / 54, C108 at
    RTC6705 pins 39/40; R80-R82 at the ESP32 end.
11. **Cosmetic / tooling:** (round 4: the TPS22810DRVR symbol has a taller body, the pin names no longer touch); the commons `sch_visual_check.py` still needs the KiCad 10 `(hide yes)` fix upstream; .kicad_pro
    `sheets` lists only Root until a GUI save; reference gaps (C3, C4, ...) kept so the parallel floorplan's refs stay
    valid (the "P4 annotation closes gaps" step is deferred).
12. **PY25Q128HA-DFH-IR quote (round 3):** the NextPCB quote must confirm U13 (the MPN is in the Puya DS Rev 2.0
    ordering table, no distributor listing found, LIBRARY.md) **before the board is frozen**; both fallbacks
    (PY25Q128HA-QVH-IR, GD25Q128EQIGR) are USON-8 4x4 and need a fallback land plus a placement change (spec §15.3,
    bom_plan U13 note).
13. **Board follow-ups from round 3 (board stage):** the next `sync_pcb.py` swaps C122 to the 0402 land (4.7 µF) and
    picks up D1's `lib:SMF5.0A` symbol link; the next `setup_board.py` run writes component class RP2350A (bom_plan
    sheet field) and the new class colours (both already in the .kicad_pro); the routing checkpoints older than
    2026-10-10 03:00 lack the LED-row / M4 silk fix: re-run `hardware/tools/silk_pad_labels.py BOARD` (round 4; the
    same table as `silk_fix3.py`, idempotent, `--check` gate; B7 / B9 fail without it).

14. **Board follow-ups from round 4 (board stage):** the next `sync_pcb.py` swaps U5 to the WSON land (move the GND via
    under pad 5 and the +BATT via under EP 7), ties U20 pin 1 to GND (clears the only DRC error) and brings parity to 0
    (scratch-verified); move C103 to B beside RTC6705 pins 31/32 and C94 / C95 to <= 1.5 mm (FLOORPLAN item 13); every
    copy of a routing checkpoint to the repo board runs `hardware/tools/silk_pad_labels.py BOARD` and check_conventions
    first (FLOORPLAN item 6). DECISIONS.md holds two rows numbered D77 (the 2026-10-09 hot-loop decision and the
    2026-10-10 inner-layer decision of the routing stage): the orchestrator renumbers the second.

## Integration decisions to log (DECISIONS.md)

- A9: MPN + Manufacturer required, LCSC where the part has one (D60); checked by check_conventions A9 and check_netlist N3.
- OpenDrone symbols with unspecified pins are used through typed project copies (lib:), not ERC exclusions.
- Every multi-pin net carries a local label (no auto-named nets on the board).
- C134 takes the next free number after C133; references stay stable (no gap closing during the parallel floorplan).
- `sch_integrate.py` is a mandatory step after any sheet generator.

## Reproduce

Round 4 (scratchpad `p2v3/p4/fix4`, generators in `fix4/gens` copied from fix3, mini repo `fix4/OpenAIO-Whoop`, `OAW_HW` selects the hardware dir):

```
scripts/lib_fix4.py HW/lib.kicad_sym ; scripts/bom_fix4.py HW/bom_plan.json ; scripts/contract_fix4.py HW/sch_contract.json
scripts/root_build.py HW ; scripts/regen.sh ; HW/tools/silk_pad_labels.py HW/OpenAIO-Whoop.kicad_pcb
scripts/spec_fix4.py research/DESIGN-SPEC.md ; scripts/docs_fix4.py research ; scripts/schematic_md_fix4.py research/SCHEMATIC.md
checks: scripts/checks.sh (ERC, check_netlist, check_conventions, svc_k10) ; frame_check.py ; check_p5_conditions.py ;
        ptest/: sync_pcb.py + kicad-cli pcb drc --schematic-parity --refill-zones (scratch board only)
```

Round 3 (scratchpad `p2v3/p4/fix3`, generators in `fix3/gens` copied from fix2, `OAW_HW` selects the hardware dir):

```
scripts/lib_fix3.py HW/lib.kicad_sym ; scripts/bom_fix3.py HW/bom_plan.json ; scripts/contract_fix3.py HW/sch_contract.json
scripts/colours_fix3.py HW ; scripts/root_build.py HW ; scripts/regen.sh ; scripts/imu_fix3.py HW/imu.kicad_sch
scripts/silk_fix3.py HW/OpenAIO-Whoop.kicad_pcb ; scripts/{spec,pinmap,floorplan,schematic_md}_fix3.py research/<file>.md
checks: kicad-cli sch erc ; check_netlist.py ; check_conventions.py ; svc_k10.py ; frame_check.py (title block) ; check_p5_conditions.py
```

Round 2 (scratchpad `p2v3/p4/fix2`, generators in `fix2/gens` copied from fix1, `OAW_HW` selects the hardware dir):

```
scripts/bom_fix2.py HW/bom_plan.json ; scripts/lib_fix2.py HW/lib.kicad_sym ; scripts/contract_fix2.py HW
scripts/patterns_fix2.py HW ; scripts/blackbox_fix2.py HW/blackbox.kicad_sch
scripts/regen.sh (esc rx osd vtx rp2350a power led pads + sch_integrate) ; scripts/root_build.py HW ; HW/tools/sch_integrate.py HW
scripts/{spec,pinmap,ioset,decisions,bomred,schematic_md}_fix2.py research/<file>.md
checks: kicad-cli sch erc ; check_netlist.py ; check_conventions.py ; svc_k10.py ; frame_check.py ; check_p5_conditions.py
```

Round 1 (scratchpad `p2v3/p4/fix1`, generators in `fix1/gens`, `OAW_HW` selects the hardware dir):

```
scripts/lib_fix.py HW ; kicad-cli sym upgrade --force HW/lib.kicad_sym
scripts/bom_fix.py HW/bom_plan.json ; scripts/contract_fix.py HW ; scripts/pro_patterns_fix1.py HW/OpenAIO-Whoop.kicad_pro
OAW_HW=HW: gens/build_esc.py --root HW/OpenAIO-Whoop.kicad_sch ; gens/power_sheet.py HW ; gens/build_rp2350a.py --hw HW
  gens/build_rx.py HW/OpenAIO-Whoop.kicad_sch ; gens/gen_vtx.py HW ; gens/build_osd.py --out-root HW ; gens/build_pads.py
scripts/root_build.py HW ; HW/tools/sch_integrate.py HW
scripts/spec_fix1.py research/DESIGN-SPEC.md ; scripts/pinmap_fix1.py research/PINMAP.md ; scripts/decisions_fix1.py research/DECISIONS.md
```

P4 integration (first build):

```
# scratchpad p2v3/p4/integrate (HW = /home/user/OpenAIO-Whoop/hardware)
scripts/retype_lib.py HW && kicad-cli sym upgrade --force HW/lib.kicad_sym
scripts/bomplan_p4i.py HW fields ; scripts/contract_p4i.py HW
gens/gen_vtx.py HW ; gens/build_rp2350a.py --hw HW ; gens/power_sheet.py HW ; gens/build_led.py HW ; gens/build_pads.py
scripts/root_build.py HW ; HW/tools/sch_integrate.py HW ; scripts/pro_patterns.py HW/OpenAIO-Whoop.kicad_pro
kicad-cli sch export netlist ... ; scripts/bomplan_p4i.py HW nets NETLIST ; scripts/docs_p4i.py research/PINMAP.md research/DESIGN-SPEC.md
kicad-cli sch erc ; HW/tools/check_netlist.py ; HW/tools/check_conventions.py ; sch_visual_check (KiCad 10 hide fix)
```

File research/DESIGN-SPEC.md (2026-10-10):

# Design spec (proposal, P0)

**Status: proposal for a board that has not been designed.** Nothing below
exists as a schematic or a layout. This file fixes the targets and the part
choices for phase P0 of [BUILD-PLAN.md](BUILD-PLAN.md). Decisions D1-D44 of
[DECISIONS.md](DECISIONS.md) are applied, including the O4 Lite support
(D13-D17), the area cuts (D18), the P0 rule of D22, the real-placement area
evidence of D23 and the decisions of review rounds 3-4 logged as D24-D44 (the
named D21 rule breaks among them). The BOM reduction of 2026-10-09 (D52-D54,
[BOM-REDUCTION.md](BOM-REDUCTION.md) §3 items BR-01 to BR-26) is applied on top:
286 → 245 placements and 89 → 76 BOM lines against the corrected baseline
(§9.4). D54 kept the owner-call items at their conservative default (OC-1 "no
AGM210MAP in rev1" was reversed by the owner's D56; the PA NTC and VTX power-down
hook, the PA_VCC selector until V5 stay; the TP10 / SWD pads became test vias or
went with D67). D45-D51 (P2 floorplan and board setup) are in DECISIONS.md and
FLOORPLAN.md and are not restated here.

**P4 schematic status (2026-10-09, binding over older text in this file).** The schematic
(`hardware/*.kicad_sch`, research/SCHEMATIC.md) implements the later owner and
orchestrator decisions; where a paragraph below still describes an earlier
variant, these win:

- **ESC stage (D56, D77):** 12x AGMSEMI AGM210MAP P+N half-bridges (one per
  phase, the Matrix II stage) with **one 10 µF X6S 0402 hot-loop capacitor per
  AGM210MAP** from pin 3 S2 (+BATT) to pin 1 S1 (GND) at the cell's lead side
  (C20 / C23 / C21 per ESC, x4); the phase-B one is also the EFM8 VDD bulk within
  4 mm of VDD pin 4. The TI CSD25310Q2 + CSD13202Q2 text of §4.3 is the documented
  fallback. Bluejay first power-up `A_X_10_96`, then `A_X_5_96` after V2.
- **USB (D57, D76):** vertical JST SH 1.0 BM04B-SRSS-TB (J31: 1 GND, 2 D−, 3 D+,
  4 VBUS, pin 1 orientation gated by V0-USB), SGM40661 OVP load switch on VBUS
  (U24), TPD2EUSB30 D+/D− ESD at the plug (D7). Pogo pads, alignment holes and the
  clip-on adapter (O3) are gone.
- **RX (D55, D58, D61):** ESP32-PICO-V3 SiP, the D0WD-V3 fallback is withdrawn;
  ELRS Wi-Fi restored with the Johanson 2450AT07A0100001T chip antenna (AE2) and
  the R88 / C132 / C133 pi match (bench-only update mode). SX1281 RFIO feeds the
  house **Johanson 2450FM07D0034T** front-end filter (matched to the SX1281,
  internally DC blocked).
- **Parts:** blackbox Puya PY25Q128HA-DFH-IR (D66); 12 MHz crystal Abracon
  ABM8-272-T3 (D78, RP2350 Table 629 ESR ≤ 50 Ω); camera plug J32 + pads (D64);
  plug-ready motor lands (D65); shared boot button SW1 (D65); test vias (D67);
  holes on 25.5 mm (D73).
- **5 V BEC (D79):** published **1.5 A continuous**; the 1.67 / 1.82 / 1.98 A
  figures are converter capability, not a rating (§5.3).
- **Power table:** +5V carries 0.70 A analog / about 0.25 A HD (the O4 is on
  +5V_BST ahead of the mux, D53 BR-10); +3V3_VTX 0.10 A typical, about 0.17 A at
  the top PA step.
- **P4 critique round 2 (2026-10-10, D81):** ELRS layout `"vtx_miso": -1` written explicitly (the stock
  23 is the PICO's flash DI); board net classes come from the .kicad_pro patterns (PA_VCC Power, U2_SW
  Phase; N6 cross-check); TPS61022 4.8 V start-up limit in the hot-plug analysis (V3c); blackbox reads at
  75 MHz (F7 / V9 read-back gate); PNP-stage numbers from the P4 ngspice run (§4.8, V5 / V8); P5
  placement conditions scripted in `hardware/tools/check_p5_conditions.py`.

**P0-close items still open:**

1. **O15**: NextPCB EQ for the 0.35 mm-pitch leadless parts. Closed: D53 dropped
   it once BR-01 to BR-04 landed, and the ESP32-D0WD-V3 fallback that kept it is
   withdrawn (D55, D61).
2. **O17**: NextPCB BOM quote by exact MPN on the full BOM (stock gate per line).
3. **O20**: the user UART pad group (TP0 RP0 5V GND) has no compliant top site at
   real size (sketch v5, §10); P2 decides between the bottom, the left edge with a
   reduced antenna-root spacing, or an owner pad lever.

**Area** is settled by D23 on the real placement (floorplan preview: 342 of 345
parts at 0.2 mm, 0 violations). The budget method stays a P2 tracking tool:
`budget_v6.py` reads **100.5 % top / 92.5 % bottom** like-for-like after the
round-4 ESC cell correction (budget v5 before it: 97.15 / 97.04 %, 7.4 / 6.7 mm²
over the 96 % figure), §9. Round 4 corrected the CSD25310Q2 pinout (source, not
drain, on the exposed pad, §4.3); the preview was drawn with the old cell, so P2
re-places the ESC cells with the phase-via strips of §4.3.

The P1 board setup was applied to the round-3 revision (`setup_board.py`, §8.4:
board-spec check 31/31, DRC 0, rules parsed, self-test 0 failures); round 4
leaves it untouched and lists what the next P1 re-apply takes over (tab T1 on the
right edge, the iron-rework rule for all parts, the ganged-mask scope, the
RTC6705 chain start; §8.4, §15.6). Round-3 BLOCKER and MAJOR findings: 23 of 23
fixed (§15.7); round 4: 10 of 10 addressed, none rejected (§15.8).
Circuit-detail values for the schematic loop are listed in §15.5 (D22, owner
P4). Every number here is a target, a datasheet value or a calculation, and each
one says which.

Date 2026-10-07, revised the same day after review rounds 1-4 (electrical,
RF and firmware, manufacturing and lineup) and decisions D12-D44; BOM reduction
D52-D54 applied 2026-10-09. Inputs: the
owner direction and owner rules (2026-10-06), [DECISIONS.md](DECISIONS.md),
the 1-2S / O4 Lite study (scratchpad `study-1-2s/RECOMMENDATION.md`), the
research tracks 00-09 (Matrix photo analysis, Matrix deep dive, landscape, ESC,
VTX/OSD, FC/RX/firmware, power/connectors/mechanics, NextPCB DFM, prior art,
OpenDrone reuse map) with their verification logs, the JLCPCB and NextPCB
capability pages, live LCSC and Digi-Key stock and temperature ratings
(2026-10-07) and [LINEUP-CONVENTIONS.md](LINEUP-CONVENTIONS.md). The competitor
material is in [COMPETITION.md](COMPETITION.md); the FC, RX and ESC pin plans
are in [PINMAP.md](PINMAP.md).

Status tags used below: **V** read from a primary source, **S** screened
(secondary source, distributor index, research track not re-derived), **I**
inferred (calculation or engineering judgement). Loss and thermal numbers come
from `calc/thermal_v3.py`, area numbers from `spec/budget_v6.py`, the
key-package floorplan from `spec/sketch_v5.py` (all scratchpad; earlier
versions kept).

---

## 1. Scope and targets

Scope is fixed by the owner decision of 2026-10-06: **1S only, match the BetaFPV
Matrix 1S 5IN1 II** in envelope and features, beat it on measured and documented
ratings, blackbox, repairability and open documentation, not by adding scope.

| Item | Target (proposal) | Basis |
|---|---|---|
| Input | 1S LiPo / LiHV, 3.0-4.35 V operating; electronics regulate down to 2.5 V cell under sag (the VTX PA is rated from 3.0 V only); 2S not supported ("1S" silk at the battery pads; D14); 2S belongs on a separate future HD-only board with 20-30 V FETs, not this PCB (D19) | owner decision; TPS61022 runs to 0.5 V once started, starts at 1.8 V (V, TI SLVSDX7D); SE5004L VCC 3.0-5.5 V (V) |
| Board body | 26.4 x 26.4 mm square (Matrix II: 26.35 mm, photo-measured) | V (01) |
| Orientation | Diamond mount like the Matrix: flight-forward points at a body corner. Front corner rounded with R 5.8 mm and carries no ear | V (01, photo); I (radius) |
| Ears and holes | 3 ears (left, right, rear corners), ring OD 4.8 mm. Holes **Ø 3.5 mm** on a **25.75 x 25.75 mm square**, non-plated cut-outs in P1; plated holes with a GND annulus are decided at P2 with the ball fit (O2, O16) | Matrix II holes Ø 3.48-3.57 on 26.0 mm, plated (V, 01). 25.75 mm halves the worst offset in 25.5 and 26.0 mm frames to 0.18 mm radial (I, from 06 §3.3) |
| Overall size | 30.55 x 30.55 mm including ears (Matrix II 30.9 mm); outline area 696.6 mm² net of holes | I (outline script, §9) |
| Mounting | 3-point soft mount with BetaFPV-type shock balls; 1.0 mm board matches the Matrix ball groove | V (01, 06 §3.3) |
| Thickness | 1.0 mm finished, 6 copper layers | §8 |
| Weight | **≤ 3.5 g** bare (solder-pad build, no battery pigtail, no antenna). Estimate 2.8-3.1 g (§6). Matrix II solder-required: 3.76 g | I (§6); V (Matrix, 01) |
| ESC | 4 channels, Bluejay on EFM8BB51 (I grade), P+N direct drive, bidirectional DShot, EDT. Stage per D56: 12x AGMSEMI AGM210MAP P+N half-bridge (PDFN 3.3x3.3, one per phase, the Matrix II stage), hot path 34.1 mΩ typ, one 10 µF hot-loop cap per AGM210MAP (D77); TI CSD25310Q2 + CSD13202Q2 (40.2 mΩ) = documented fallback | §4.3, §4.4 |
| ESC rating to publish | **Measured only, by protocol V4 (§14)**: continuous A per channel (one channel loaded, others 2 A) and on all four, with the stated airflow, 25 °C ambient, VTX 25 mW, every part inside its own rating; burst duration at 12 A and 18 A from the measured hover steady state. No number above the model is claimed. Model (`thermal_v3.py`, PA-case term included), one channel / all four: h 80 W/m²K 4.7-5.1 / 2.8-3.3 A; h 64 1.8-3.7 / 1.9-2.5 A; h 55 0-1.4 / 1.2-1.8 A; at h 30 the board is out of rating at hover. The D20 figures (study model without the PA-case term, h 64-80) are 4.3-5.2 / 3.0-3.8 A. HD mode (analog VTX off, D17): 4.9-5.6 / 3.5-4.1 A at h 64-80. With the heat levers of §5.4: 4.7 / 2.9-3.0 A at h 55. Bursts to FET 110 °C: 12 A for 1.3-4.2 s at h 80 and 0-2.4 s at h 55; 18 A under 0.5 s. The Matrix stage on the same model: 5.7-5.9 / 3.2-3.8 A at h 80, 12 A for 5.5-7.3 s. The D12 stage is **not** better than the Matrix's; what the board offers is a published protocol, the same rig on a Matrix II, and the numbers | §4.3, §5.4 |
| VTX | RTC6705 + Skyworks SE5004L PA on the cell, U.FL. **Levels as ELRS pushes them** (five, fixed in `freqTable.h`, V): `0` (PA biased at minimum drive, not pit), `RCE` (pit at boot, then 25 mW), `25`, `100`, `400`. 25 and 100 mW are closed loop on the PA detector; `400` is open-loop full drive (ELRS YOLO setpoint) behind a hardware **power ceiling** of 27 dBm at the U.FL (§4.8) and is published as "max (measured, power-limited)" per board: 400 mW is **not** guaranteed at sag or hot, and the closed-loop 400 mW patch is O6 gate 2. **Channels:** ELRS pushes 48; the patched firmware refuses the L band (5362-5621 MHz) and holds pit (O6 gate 5); the 40 channels from 5645 to 5945 MHz are supported, the 24 inside both datasheet bands (RTC6705 5725-5865, SE5004L 5150-5850 MHz) are rated, the other 16 published as measured after the lock check of V5. "Max" is continuous only at high airflow (hover needs h ≥ 63-82 W/m²K, §4.3). In HD mode the analog VTX is held off in hardware (D17) | §4.8 |
| Digital VTX | DJI O4 Lite on solder pads **VHD GND TX1 RX1** (D13, D16): hardware UART1 with MSP DisplayPort, supply +5V_HD from the 5 V boost output `+5V_BST` (ahead of the USB mux, D53 BR-10) through a TPS22810 load switch enabled by FC PINIO1 (GPIO27) and a filtered cell threshold with hysteresis (on at a cell of 3.23-3.82 V, shed at 2.74-3.14 V with 1 % resistors and +5V_HD 4.93-5.37 V; POWER P4-1; D15, BR-22, §4.2); no SBUS pad. One video system at a time: the HD line also holds the RTC6705 and the PA reference off (D17) | §4.2, §4.8, PINMAP |
| OSD | Analog: Betaflight PIO framebuffer OSD on the RP2354A (no OSD chip). It overlays on the camera's sync and generates none: no camera, no OSD (the Matrix's AT7456E free-runs). HD: MSP DisplayPort canvas on the O4 | §4.5, §4.8 |
| RX | Serial ExpressLRS 2.4 GHz, ESP32-PICO-V3 (in-package flash and 40 MHz crystal; D52 BR-01, D55; the D0WD-V3 fallback is withdrawn, D61) + SX1281 (BR-25), +13 dBm, no PA/LNA (Matrix parity), Johanson 2450FM07D0034T front-end filter, insulated wire monopole trimmed to resonance. **ELRS Wi-Fi restored (D58):** Johanson 2450AT07A0100001T chip antenna (AE2) at a board edge with the R88 / C132 / C133 pi match; Wi-Fi is a bench-only update mode (disarmed, +3V3 peak 0.48 A); updates also through Betaflight serial passthrough | §4.7 |
| FC | RP2354A, Betaflight ≥ 2026.6.2, one gyro per revision published in the target (no lottery) | §4.5, §4.6 |
| Blackbox | 16 MB SPI NOR, Puya PY25Q128HA-DFH-IR (D66; JEDEC 0x852018 is in Betaflight's m25p16 table), SPI0 | §4.9 |
| 5 V BEC | 5.15 V nominal at the boost (4.93-5.37 V worst case). **Published: 1.5 A continuous (D79)**: above 1.5 A the TPS61022 needs ≥ 20 µF effective COUT (DS 6.3), which the four 22 µF 0603 meet only typically. Converter capability (not a rating), calculated nominal peak **1.67 A at 2.8 V, 1.82 A at 3.0 V, 1.98 A at 3.2 V** in (TI method, −30 % inductance, peak at 80 % of Isat, η 0.85 / 0.86 / 0.87). Design loads: analog 0.70 A; HD 1.43-1.48 A (O4 + FC + RX + buzzer; LED strip and user 5 V not budgeted in HD mode, 1.73 A with them). Published per VIN and board temperature from V1 (TPS61022 TJ ≤ 125 °C) | §4.2, §5.3 |
| Current / voltage sense | 0.5 mΩ shunt (four-pad Kelvin land, net-tie) + INA186A3 (50 mV/A, `ibata_scale` 500), VBAT 1:1 divider; scales measured and set in the target | §4.1 |
| Connectors | BT2.0 pigtail on two plated holes (user-fitted); 4 plug-ready motor lands (solder or optional Molex PicoBlade header, D65); **USB on a vertical JST SH 1.0 BM04B-SRSS-TB** (D57, D76) with SGM40661 VBUS OVP and TPD2EUSB30 D+/D− ESD on the board; **camera on CAM 5V GND pads plus a JST 0.8 mm SM03B-SURS-TF plug** (D64); U.FL for the VTX; RX antenna wire hole; user UART pads **TP0 RP0** (PIOUART0) with 5V GND (site open, O20); LED, BZ+ BZ-; O4 pads VHD GND TX1 RX1 | §4.10 |
| Fab / assembly | NextPCB turnkey (partial turnkey with consigned lines), DFM-compatible with JLCPCB except silk legibility (0.8 mm labels, D12; owner sign-off for this board pending, O11); through vias only, OpenDrone 0.35/0.20 via (D6); deliberate rule breaks as named, scoped DRU rules (D21) | §8, §15 |

---

## 2. What to optimise, ranked

| Rank | Goal | Metric | Target | Bench measurement |
|---|---|---|---|---|
| 1 | Electronics rail that survives sag (no FC/RX brown-out; video to 3.0 V, the PA minimum) | +5V at full design load (analog 0.70 A; HD 1.48 A) while the input is swept 4.35 → 2.6 V | analog: ≥ 4.85 V at VIN ≥ 2.8 V (setpoint 5.15 V, worst-case low corner 4.93 V less the mux drop); HD: ≥ 4.75 V down to the O4 shed threshold (2.74-3.14 V cell), the O4 shed before +5V drops further; ripple ≤ 50 mV p-p (forced PWM, 1 MHz); no reset of FC or RX down to VIN 2.5 V, on USB hot-plug or on unplug | bench supply + electronic load, scope at the camera pad and on +5V |
| 2 | Honest ESC rating, measured on the same rig as a Matrix II | continuous A per channel with every part inside its rating, measured at the part (hottest FET ≤ 100 °C, EFM8 ≤ 125 °C, RTC6705 case ≤ 80 °C, RP2354A, gyro, SX1281, NOR, ESP32-PICO-V3 (in-package flash), crystals, TCXO and SE5004L case ≤ 85 °C, TPS61022 TJ ≤ 125 °C, X6S caps in the cells ≤ 105 °C) under V4; burst durations | published as measured with the airflow stated; no claim above the model (§1). Cost of D12 against the Matrix stage: path 40.2 mΩ typ (48.8 max) vs 34.1 (50.0 max); model −0.8 to −1.0 A continuous and a quarter to a half of the 12 A burst time at the same airflow | thermocouples per V4; same rig on a Matrix II |
| 3 | Weight | grams on a 0.01 g scale | ≤ 3.5 g bare (Matrix 3.76 g) | scale, first 5 prototypes |
| 4 | Measured VTX power and clean spectrum | output per channel at 25/100/max at 3.7 V; 2nd harmonic | 100 mW within ±3 dB unit to unit at 5850 MHz without calibration; 25 mW: unit spread measured and published from V5 (the detector rise at 14 dBm is within the uncalibrated ADC error, so no uncalibrated tolerance is claimed); ±1.5 dB at both levels only with per-unit calibration (patch 8); max ≤ 27 dBm at the U.FL on every unit (power ceiling); at 5650/5750/5945 MHz ±3 dB on the sample after the ELRS interpolation fix; full per-channel table and the unit spread published; 2f ≤ −30 dBm (EN 300 440 limit) | calibrated power sensor + 30 dB attenuator; spectrum analyser to ≥ 18 GHz; ≥ 5 boards |
| 5 | RX link | conducted sensitivity at 500 Hz packet rate; desense with every on-board aggressor active | within 2 dB of the SX1281 datasheet figure; ≤ 3 dB desense | ELRS link stats + attenuator chain |
| 6 | Gyro noise | hover pre-filter gyro noise from blackbox | ≤ the Matrix II on the same frame and motors | 60 s hover logs, FFT |
| 7 | Crash survival | BetaFPV wall test (5 m run, 20 hits) | 0 of 4 boards damaged, ears included (Matrix II on Air75 II: 2 of 4) | BetaFPV protocol [01] |
| 8 | Repairability and openness | test access, documentation | C2 pads per ESC, SWD, FC and RX boot pads, full schematic/BOM/pinout, repair map | review at P7 |
| 9 | Upstream firmware | merged targets | Betaflight target in betaflight/config, ELRS target JSON, stock Bluejay build (no custom hex) before release | PR merge |

---

## 3. Class bars

| | BetaFPV Matrix 1S 5IN1 II | FusionFPV UD 4IN1 (prototype, [fusionfpv.com/aio](https://fusionfpv.com/aio/)) | OpenAIO-Whoop target |
|---|---|---|---|
| Size, mount | 26.35 mm body, 30.9 mm with 3 ears, 26 mm 3-point | 39.32 x 25.76 mm, undermount racer | 26.4 mm body, 30.55 mm with 3 ears, 25.75 mm 3-point |
| PCB | 1.0 mm, layers not published | 4 layers, 0.8 mm, high-Tg | 6 layers, 1.0 mm, through vias |
| Weight | 3.76 g (pads) / 4.13 g (plugs) | n/p | ≤ 3.5 g (pads) |
| FC | STM32G473 + AT7456E OSD | STM32G473CEU6 + AT7456E | RP2354A + PIO OSD (needs camera sync) |
| Gyro | 6-part lottery | BMI270, own supply | one part per revision (BMI270 or ICM-42688-P after fly-off) |
| ESC | 4x BB51, 12x AGM210MAP P+N (34 mΩ), "12 A cont / 18 A peak" | 4x BB51, 12x SiA517DJ, 5 A design target | 4x BB51, 12x AGM210MAP P+N (34 mΩ, D56) with one hot-loop cap each (D77), rated by measurement only (V4) |
| RX | ESP8285 + SX1281 onboard | external | ESP32-PICO-V3 + SX1281 onboard, ELRS 4.x mainline |
| VTX | RTC6705 + RFPA5542 (EOL) + MM32F003, 25-400 mW | RTC6705 + RTC6659-class PA, 25/100/250/MAX | RTC6705 + SE5004L, no VTX MCU (ELRS drives it), 0/RCE/25/100/max (power-limited; 400 closed loop after O6) |
| Digital VTX | separate 3IN1 HD board | n/p | O4 Lite pads + switched supply on the same board, one system at a time (D13-D17) |
| Blackbox | 16 MB | 16 MB | 16 MB |
| USB | SH1.0 vertical + adapter | 4 pogo pads + clip-on adapter | SH1.0 vertical (BetaFPV adapter compatible, D57 / D76) with VBUS OVP and D+/D− ESD on the board |
| Openness | none | page only | schematic, layout, BOM, measured ratings |

---

## 4. Architecture per block

Each block gives the options weighed, the decision, the key parts and the
numbers. **Stock gate.** The P0 gate is "≥ 5x the 50-board quantity" (250 for a
part used once per board) **at the distributors NextPCB turnkey buys from**: HQ
Online plus its quote engine (Digi-Key, Mouser, Element14, Avnet, ...), not
LCSC (track 07 §3). The figures below are LCSC live reads on 2026-10-07 unless
marked; they are a first screen only. P0 closes with a NextPCB BOM quote by
exact MPN on the full BOM (O17); lines it cannot fill get a per-line decision
(§15.3, D60: stock and consignment no longer block a part). Parts already manufactured on an
OpenDrone board are marked **[PU]** (PARTS-USED.md). BOM symbols of parts with
no LCSC listing carry `LCSC = none (<distributor> <PN>)`, which the LINEUP A9
checker accepts as a filled field.

**Temperature grades** (V, LCSC/maker listings 2026-10-07, unless marked).
The board limit is set by the 85 °C parts at their local board temperature. There
is no placement halo (D69: H1 / H3 are void), so a part next to a FET group or the
PA is rated at that local temperature; V4 places its thermocouples at the 85 °C
parts nearest the FET groups and the PA:

| Grade | Parts |
|---|---|
| 85 °C (bind the board) | RP2354A (ambient), BMI270, SX1281, Puya PY25Q128HA-DFH-IR (−40..85, D66), **ESP32-PICO-V3** (−40..85 ambient, set by its in-package flash; V, Espressif PICO series datasheet v1.3; D55, no placement halo, D69), SE5004L (case), RTC6705 (Tj −40..85, so case ≤ about 80 °C), Abracon ABM8-272-T3 12 MHz crystal (−40..85, D78) and Yajingxin 8 MHz crystal (−40..85), YXC 52 MHz TCXO (−30..85), Walsin BPF and Johanson 2450FM07D0034T front-end filter (−40..85, D80), XINGLIGHT LEDs (−40..85; RGB −20..85), JST BM04B-SRSS-TB USB and SM03B-SURS-TF camera plugs (−25..85, S, JST catalogue), X5R capacitors (no zone rule under D69; V4 logs the hottest) |
| 90 °C | Hirose U.FL |
| ≥ 105 °C | X6S capacitors in every ESC quarter and at the PA (Murata GRM033C81E104KE14D, GRM033C81A105ME05D, GRM188C80J226ME15D, GRM155C80J106ME11D; −55..105 °C, V/S maker data via distributors; D52 BR-18 moves every 100 nF to the X6S GRM033C81E104KE14D and BR-20 retires GRM155C81A225KE11D); X7R 10 nF GRM033R71A103KA01D (BR-19, −55..125); TPS2116 and TPS22810 (TA −40..105, V); EFM8BB51 I grade, TPS61022 and the LDOs (TJ 125); SN74LVC1G3157, TLV7031, INA186 (125); FETs, BC857BM (S), diodes (150); resistors, NTC, ferrite (125-155) |

The TOGNJING 12 MHz crystal of the house FC sheet is rated −20..70 °C (V,
LCSC C37635340) and is replaced (§4.5). The BR-01 fallback parts (ESP32-D0WD-V3,
GD25Q32EEIGR, 40 MHz crystal) are withdrawn (D55 / D61) and no longer rated here.

### 4.1 Input and protection

| Option considered | Verdict |
|---|---|
| Reverse-polarity FET | **No.** The BT2.0 key protects the plug, not the user-fitted pigtail joint. A pigtail soldered reversed forward-biases the unidirectional SMF5.0A and the 12 N/P body-diode pairs (GND → N body diode → phase → P body diode → +BATT), which clamp +BATT at about −1 to −1.4 V while they short the battery at tens of amps (I): the TVS, FETs or traces fail and the board is lost. An ideal-diode P-FET (1-2 mΩ, 3x3) costs about 12 mm² and 0.4-0.6 W at 20 A. Rev1 keeps user fit (Matrix-style pads) and states the risk: + and − silk at the pads and a polarity photo in the README. Factory fitting on NextPCB's THT line is priced as a P7 option |
| TVS at the pads | **Yes, for the FET drain-source ratings only.** Event: battery unplugged (or pigtail torn in a crash) while the props spin; Bluejay damping returns rotor energy (up to about 0.3 J per motor at 40,000 rpm, I; up to about 1.2 J for four) into a bus that then holds only the MLCCs. The SMF5.0A (VBR 6.40-7.00 V at 10 mA, VC 9.2 V at 21.7 A, 200 W 10/1000 µs, V) absorbs about 0.29 J per rated pulse (I), so it covers one motor's worth, not four; the rest goes into winding and body-diode losses (I). V3b measures TVS current, duration and clamp energy; the fallback is the 400 W Littelfuse SMAJ5.0A (SMA, S; +7 mm² bottom). The fitted AGM210MAP stage (D56; V, DS VER2.73 Table 1: VDS 20 / −20 V, VGS ±12 V, EAS 36 / 49 mJ for N / P) stays in rating at the 9.2 V clamp: 9.2 V plus 2-4 V of switching overshoot is ≤ 13.2 V against 20 V, and the gates, driven at VDD = bus, see ≤ 9.2 V against ±12 V. It does not protect the parts rated below the clamp (POWER sheet D1 note): EFM8 VDD (5.5 V abs max), SE5004L VCC3 (6 V), TPS61022 (7 V; its pass-through carries a surge onto `+5V_BST`), the TPS2116 (6 V abs max) and the LP5912s (7 V) behind it, and the 6.3 V MLCCs. TI fallback stage only (D12 pair, if the AGM210MAP is replaced): the clamp would not keep the 12 V CSD13202Q2 in rating (9.2 V plus overshoot can pass 12 V; EAS 20 mJ, V SLPS313A, far below a 0.3 J event) and a 9.2 V bus exceeds its ±8 V gates. A clamp per EFM8 is not possible in this topology (VDD must follow the P sources). Accepted as Matrix parity (same topology); risk in §15.4, surge measured in V3b |
| Bulk at the pads | 2x 22 µF 0603 16 V (X5R, at the battery pads outside the ESC quarters). Board total about 55-80 µF effective at 4.35 V (table below), which shares the PWM ripple with the 30-60 mΩ battery path (03 §11). **Hot plug** (I): the MLCC-only bus against the pack and pigtail (50-80 nH, 25-35 mΩ) has ζ about 0.4-0.5, so plugging a fresh 4.35 V pack overshoots 15-25 % to 5.0-5.4 V at the EFM8 VDD (abs max 5.5 V) and the 6.3 V MLCCs, and above the TPS61022's 4.8 V VIN limit for a start-up with its output pre-biased below 0.7 V (SLVSDX7D §6.3 recommended operating conditions; 5.5 V otherwise, 7 V abs max), which is exactly hot plug (EN = VIN, +5V_BST starts from 0 V); the TVS (VBR ≥ 6.4 V) does not act. V3c tests it; the damping fallback is a polymer or tantalum bulk with ESR near the bus impedance √(L/C) ≈ 30 mΩ (about 100 µF 6.3 V, +6-10 mm² bottom) at the pads |

Effective capacitance (I: typical DC-bias behaviour including −20 % tolerance;
replaced by the Murata/Samsung simulator curves in P3):

| Part | Use | At | Effective each |
|---|---|---|---|
| CL10A226MO7JZNC 22 µF 16 V 0603 X5R | pad bulk x2 | 4.35 V | about 9-13 µF |
| GRM188C80J226ME15D 22 µF 6.3 V 0603 X6S | boost Cin x1 (the 22 µF ESC cell bulk of D52 became three 10 µF 0402 per ESC, D77) | 4.35 V | about 7-10 µF |
| GRM188C80J226ME15D | boost Cout x4 (D15) | 5.15 V | about 5-7 µF (20-28 µF for four) |
| GRM155C80J106ME11D 10 µF 6.3 V 0402 X6S | ESC hot-loop caps x12 (D77: one per AGM210MAP, pin 3 to pin 1 at the lead side; the phase-B one per ESC is also the EFM8 VDD bulk within 4 mm of VDD pin 4); the ESC3-only C30 is deleted | 4.35-5.25 V | about 2.6-2.8 µF at 4.2 V (Murata curve: 3.5 µF at 3.3 V, 2.0 µF at 5 V; EFM8 datasheet asks 1 µF) |
| GRM033C81A105ME05D 1 µF 10 V 0201 X6S | round-2 EFM8 VDD part, now fallback | 4.35 V | about 0.4-0.6 µF |

D52 BR-05 deletes the 2.2 µF EFM8 VDD caps of ESC1, ESC2 and ESC4 (their 22 µF
local bulk moves next to VDD pin 4, the 100 nF stays at the pin): the bus loses
3.0-4.2 µF effective, BR-20 gives back about 1.5-2 µF at C30 (I). V3c (hot plug)
checks it; PE-8 (pad bulk → GRM188C80J226ME15D) waits for V3c, because with
BR-05 its inferred hot-plug peak reaches 5.58-5.64 V against the EFM8's 5.5 V
(BOM-REDUCTION §5.2, §6 item 11). D77 (P4 critique) then replaced each ESC's
22 µF 0603 by three 10 µF 0402, one at each AGM210MAP's lead side (3x 2.6-2.8 µF
= 7.8-8.4 µF against 7-10 µF effective: bus capacitance about equal, V3c unchanged),
and deleted C30.

Bus ripple, caps-only upper bound ΔV = I·D(1−D)/(f·C): one ESC at 12 A and D 0.5
gives 0.4-0.6 V p-p at 96 kHz (the D12 start build, §4.4) and 0.8-1.25 V at
48 kHz on 50-80 µF; the battery path in parallel roughly halves it. The ripple is
common to the P-FET source and gate because each EFM8 sits on its own cluster's
+BATT (§4.4); it sets the EFM8 VDD peak and logic-high margin (§4.4, PINMAP F4)
and matters for the PA supply (§4.8, V5b).

| Function | Primary | Fallback |
|---|---|---|
| TVS | Littelfuse **SMF5.0A**, SOD-123FL, C151296, 33,500 (V) | Littelfuse SMAJ5.0A, SMA, 400 W (S), if V3b exceeds the SMF5.0A curve |
| Pad bulk | Samsung **CL10A226MO7JZNC** 22 µF 16 V 0603, C2762594, 457,735 [PU] | Murata GRM188R61C226ME15 (S) |
| Shunt | Stackpole **HCS1206FTL500**, 0.5 mΩ 2 W 1206, C346511, 1,717 | Yezhan ASR-S-3-0.2F 0.2 mΩ 2512, C695806, 1,020 [PU] (larger land, scale 200) |
| Current amp | TI **INA186A3IDCKR**, SC-70-6, gain 100, C2058245, 5,715 [PU] | TI INA186A3 DSBGA (YFD) (S, −4.8 mm²) |
| VBAT divider | 2x 10 kΩ 0201 (Yageo RC0201FR-0710KL, C106225 [PU]) + 100 nF | Uni-Royal 0201WMF1002TEE (S) |

Nets: the battery pads, TVS and pad bulk sit on **`+BATT_IN`** (net class VBAT,
`PWR_FLAG`); after the shunt the rail is **`+BATT`**. The Kelvin taps are their
own nets **`SHUNT_SENSE_P` / `SHUNT_SENSE_N`** (class Analog), separated from
`+BATT_IN` / `+BATT` by a net-tie in the four-pad shunt footprint, routed as a
pair on L1 or L6 away from the power current and never on In2/In3. Everything that draws
current, including the boost VIN and the PA VCC, taps `+BATT` after the shunt,
so the INA186 sees it. Numbers: 0.5 mΩ x 100 V/V = 50 mV/A, full scale 66 A at
3.3 V, Betaflight `ibata_scale` 500 (0.1 mV/A units). Shunt loss 0.2 W at 20 A,
0.31 W at 25 A. VBAT 10k/10k puts 4.35 V at 2.18 V on the ADC. Current sense is
high side with Kelvin taps and the matched input RC network of the OpenESC
Rev3.2 / OpenAIO root sheet (values moved to 0201), less its two common-mode
capacitors (D52 BR-07): 1 kΩ + 1 kΩ series and 1 µF differential (80 Hz), plus
the output RC to the ADC; any offset shows in the `ibata_scale` check. The land is a four-pad
Kelvin pattern per the Stackpole HCS application note with the sense taps at the
inner pad edges (net-tie footprint); the scale is checked on every prototype and on a sample of each
production lot (±10-20 % unit to unit otherwise, I).

### 4.2 Power tree

```
BT2.0 -> +BATT_IN pads -- SMF5.0A, 2x22u -- shunt (Kelvin SHUNT_SENSE_P/N -> INA186) -- +BATT
  +BATT -> 4x ESC power stages; 4x EFM8 VDD on their own cluster's +BATT (100n X6S at the pin, no series R;
             one 10u X6S 0402 hot-loop cap per AGM210MAP (pin 3 S2 to pin 1 S1), the phase-B one within 4 mm of VDD; D77)
  +BATT -> SE5004L PA VCC (10u X6S + per-pin 1n/100p)   [3-pad 0 ohm selector: +BATT (default) or +5V]
  +BATT -> TPS61022 boost, 1 MHz, 0.68 uH -> +5V_BST (5.15 V: FB 47k/6.2k, 4x 22u X6S 0603)
             EN tied to VIN (enabled whenever the cell is above UVLO; BR-11).  MODE = VOUT: forced PWM
  VBUS (J31 JST SH pin 4, D57) -> SGM40661 OVP (U24, 100n at IN; trips 5.75-6.12 V) -> +5V_USB
  USB D+/D- -> TPD2EUSB30 (D7, at J31) -> 27R -> RP2354A
  +5V_USB -> TPS2116 VIN1 = MODE (10u X6S at VIN1, BR-20; priority while VBUS > 3.44-4.04 V; PR1 = 27.4k/10k from VIN1)
  +5V_BST             -> TPS2116 VIN2      -> +5V (10u X6S 0402)
  +5V_BST             -> TPS22810 load switch (CIN = boost Cout C8-C11, U5 VIN within 3 mm; C17 deleted), CT 10n -> +5V_HD -> pad VHD (O4 Lite)   [D53 BR-10: ahead of the mux]
                      EN/UVLO = +BATT divider 33k/18k + 510k from +5V_HD (hysteresis) + 100n to GND (filter; BR-22):
                                on at 3.23-3.82 V rising, shed at 2.74-3.14 V falling (1 % R, POWER P4-1)
                                AND PINIO1 (GPIO27 through a BAS16LD PN diode, pull-down only; 2.4k on GPIO27, BR-24)
                      (no USB term: the mux never back-feeds +5V_BST from USB, so USB cannot reach the O4)
             +5V -> ferrite 0201 + 10u -> CAM 5V pad
             +5V -> buzzer +, user 5V pad (also the LED-strip 5V; strip data driven direct from GPIO8, BR-04)
             +5V -> LP5912-3.3 (EN = +5V) -> +3V3 (RP2354A, NOR, OSD front end, INA186, LEDs, ESP32-PICO-V3, SX1281, RGB LED)
                      +3V3 -> TPS7A2018 (EN = +3V3) -> +1V8 (gyro)
             +5V -> LP5912-3.3 (EN: 100k to +3V3, ESP32 GPIO21 via 1k; HD gate AP1606 pulls it low) -> +3V3_VTX
                      +3V3_VTX -> RTC6705, PNP PA drive stage (BR-02)
                      +3V3_VTX -> LP5907-2.85 (EN = ESP32 GPIO2 direct, internal 1M pull-down; BR-03, BR-12) -> PA VREF
             (both LP5912 inputs share one 10u X6S 0402 between their IN pins, BR-14)
  RP2354A internal core SMPS -> +1V1 (3.3 uH 2016, per RPi guide)
```

Enables: no EN floats and no EN net is shared between rails (commons
checklist). TPS61022 MODE goes to VOUT, so forced PWM holds over the whole sag
range (VMODE_H 1.2 V valid with VOUT > 2.2 V, V). The TPS61022 passes VIN to
VOUT when VIN > VOUT (V): a bus surge reaches +5V_BST and, through the mux, +5V
(§4.1).

**USB, battery or both: a power mux, not a diode.** +5V comes from a TI
**TPS2116** 2:1 power mux in priority mode (V, SLVSFG1A §7.3.1, §7.6.1.1):
MODE is tied to VIN1 = `+5V_USB`, which is selected while VBUS is above
3.44-4.04 V (PR1 divider 27.4 kΩ / 10 kΩ against VREF 0.92-1.08 V); VIN2 = the
boost output `+5V_BST` otherwise. With no USB, MODE = VIN1 ≈ 0 V puts the part
in its "MODE ≤ 0.35 V, PR1 low" row, which passes the higher input, i.e. VIN2.
The mux blocks reverse current on both channels (RCB: an input is never back-fed
from VOUT; the unselected input stays off even when it is the higher one, the
priority row "VIN2 = X"), so USB and the boost output never meet, and the boost
stays enabled in every case:

- **Cell and USB:** +5V runs from USB; the boost idles on its own output. It
  cannot charge the cell from USB, because the forced-PWM reverse flow of
  §7.4.1 needs its output driven above the setpoint, which the mux prevents.
- **Plugging USB in with a cell fitted:** PR1 crosses VREF at VBUS 3.44-4.04 V;
  the break-before-make switchover (8 µs at 5 V, V) then waits until VBUS is
  within 42 mV of +5V before the USB channel closes (RCB, V §7.6.1), so +5V
  sags from 5.15 V until it meets the rising VBUS: a few tenths of a volt on a
  fast plug-in, down to about 3.5 V if VBUS takes 1 ms to rise (I). The O4 sits
  on `+5V_BST` ahead of the mux (D53 BR-10), so its current never crosses the
  mux and the load seen here is the analog 0.42-0.70 A.
- **Unplugging USB with a cell fitted:** +5V follows the collapsing VBUS through
  the closed USB channel until PR1 falls below VREF (VBUS 3.44-4.04 V), then
  the 8 µs gap adds I·t/C = 0.7 A x 8 µs / 20 µF ≈ 0.3 V: **+5V minimum about
  3.1-3.7 V for tens of µs** before the running boost takes over (I). The
  LP5912-3.3 drops at most 180 mV at 500 mA (V), so +3V3 stays ≥ about 3.0 V.
  Round 3's 232 kΩ / 100 kΩ divider switched at 3.05-3.58 V and let +5V fall to
  about 2.75 V. V1 case (b) scopes +5V and +3V3 on 20 unplugs: no FC or RX
  reset.
- **USB only:** DShot idle-high back-feeds +BATT to about 2.5-2.8 V (PINMAP
  F16). The boost may start and hiccup on that weak source, but its output is
  not selected while USB is present, so +5V is unaffected; the EFM8 brown-out
  cycling stays a V9 item.
- **Battery only:** VIN1 floats except for the mux's reverse leakage out of an
  unselected input (0.001 / 0.05 / 0.15 µA at 25 / 85 / 105 °C, **typical
  values; the datasheet gives no maximum**) and the MODE and PR1 pin leakage
  (≤ 0.1 µA each, V), all into the 37.4 kΩ PR1 divider: about 10 mV typical, and
  0.3 V even at 50 times the typical IREV (I). Nothing senses that node any
  more (the round-4 AP1606 USB term is gone, BR-10), so it only has to stay
  below the mux's own thresholds.

**O4 supply ahead of the mux (D53 BR-10).** The TPS22810 takes its VIN from
`+5V_BST`, the boost output at TPS2116 VIN2, not from `+5V`. The mux blocks
reverse current on both channels (above), so USB never reaches `+5V_BST` and
the O4 cannot load a PC port, by topology: on USB only `+5V_BST` carries at
most the hiccuping, back-fed boost (§4.2 USB only), and the cell threshold
below keeps the switch off at the back-fed 2.5-2.8 V. This
replaces round 4's USB term (an AP1606 on the EN, gate on `+5V_USB`), which is
deleted. With a cell and USB both present the O4 runs from the boost, as in
battery-only operation, and its 1.0-1.2 A no longer crosses the mux (about
0.05-0.07 W saved); V1 checks USB + cell + HD mode. The switch's own CIN
(C17) is deleted (D79): the boost output caps C8-C11 are its input capacitor under the P5
condition 'U5 VIN within 3 mm of C8-C11 or U3 VIN2' (TPS22810 DS 10.3: CIN optional, 1 µF usually
sufficient), checked by `hardware/tools/check_p5_conditions.py`; floorplan v3 misses it (6.1 mm), so P5
moves U5 or puts back a 1 µF 0201 (GRM033R61A105ME44D, existing line). The O4 switch's two EN terms (D15):

- **Cell threshold:** a +BATT divider on the TPS22810's own EN/UVLO comparator
  (VENF 1.08-1.18 V, VENR 1.13-1.30 V, EN leakage ≤ 0.1 µA, V SLVSDH0C). The
  comparator alone is not enough on this bus (round 4): its falling-edge
  deglitch is only 2.5 µs typical and TI asks for an EN-to-GND capacitor "when the
  supply is particularly noisy" (V, §9.3.3); +BATT carries the ESC ripple
  (0.4-0.6 V p-p for one ESC at 12 A, roughly halved by the battery path, §4.1),
  which the divider puts at EN as 0.08-0.23 V p-p against a typical comparator
  hysteresis of 0.10 V; the VENF and VENR ranges overlap, so no minimum
  hysteresis is guaranteed; and shedding the O4 removes about 2.3 A of cell
  current, so the cell rebounds by 0.17-0.31 V across the pack and pigtail
  resistance (I), as much as or more than the comparator's own hysteresis at
  the cell (about 0.13-0.31 V): without help the switch trips on ripple troughs 0.1-0.3 V
  early and cycles on and off at the threshold, each restart a new inrush. The
  network is therefore (values from D53 BR-22; round 4 had 90.9k / 49.9k / 1.5M
  for the same thresholds):
  - divider **33 kΩ / 18 kΩ** (Yageo RC0201FR-0733KL / RC0201FR-0718KL);
  - **510 kΩ** from `+5V_HD` to EN (Yageo RC0201FR-07510KL): with the switch on
    it adds 0.115 V at EN, about **0.333 V at the cell**, and with the switch off
    (+5V_HD discharged by QOD) it pulls the other way, so the hysteresis is at
    least the resistor's 0.333 V even for a part with no comparator hysteresis,
    which covers the 0.17-0.31 V rebound;
  - **100 nF** EN to GND (Murata GRM033C81E104KE14D, the leg-cap part): with the
    11.4 kΩ Thevenin source τ ≈ 1.1 ms (corner about 140 Hz), about 57 dB at
    96 kHz, so the ripple at EN falls below 0.4 mV; τ also sets how long a short
    punch sag rides through before the shed, a trade inside D15 that V1 confirms
    (1-10 ms).
  The divider draws 82 µA from a 4.2 V cell (round 4: 30 µA), negligible against
  a live board. The O4 is switched on at **3.23-3.82 V rising** and shed at **2.74-3.14 V
  falling** (V: TPS22810 VENR 1.13-1.30 V / VENF 1.08-1.18 V with R9 33k, R10 18k, R87 510k at 1 % and
  +5V_HD 4.93-5.37 V, POWER sheet P4-1; nominal resistors give 3.27-3.77 / 2.78-3.10 V; V1 sets the exact point):
  a shed stays latched until the resting cell has recovered (landing or low
  throttle), which the README states, and a fresh or storage-charged pack
  (≥ 3.8 V) always starts the O4. On USB only the back-fed 2.5-2.8 V puts EN at
  0.86-0.97 V, below VENR, as a second guard.
- **PINIO1 (GPIO27):** a Nexperia **BAS16LD** PN switching diode (anode on EN,
  cathode on GPIO27) can only pull EN down, and GPIO27 carries a **2.4 kΩ**
  pull-down (Ralec RTT012401FTH, the DShot line; D53 BR-24, was 4.7 kΩ).
  GPIO27 low or not yet driven (FC in reset, SD build, USB): EN ≤ VF (about
  0.6 V at the 80-90 µA the 11.4 kΩ divider source delivers; VF ≤ 715 mV at 1 mA, V)
  + about 0.2 V across the pull-down = **≤ 0.87 V against VENF ≥ 1.08 V** (the BOM
  study verified 0.81-0.87 V with a 3.3 kΩ pull-down; 2.4 kΩ only lowers it; P4
  recomputes it once, §15.5 P4-1). GPIO27 high:
  the diode is reverse-biased by ≥ 1.6 V and its leakage (≤ 30 nA at 25 V and
  25 °C, ≤ 30 µA at 150 °C, V Nexperia BAS16LD Table 7; about 1 µA or less at
  85-105 °C, I) moves EN by ≤ 0.012 V, the shed point by ≤ 0.04 V. The diode also
  discharges the 100 nF EN filter: GPIO27 driven low empties it in microseconds,
  the 2.4 kΩ pull-down (FC in reset) in about 0.3 ms; turning on from the clamped
  0.8-0.87 V takes about 1-3 ms (I). The round-3
  Schottky (SDM02U30LP3: IR ≤ 7 µA at 10 V and 25 °C, typical curve 10-100x
  higher at 85-125 °C, V Diodes Fig. 3) into a 61.8 kΩ source would have lifted
  EN by 0.6 V or more on a warm board, so the O4 would never have been shed: the
  same failure class as the round-2 USB OR diode. The RP2350's own reset
  pull-down (tens of kΩ) is not enough on its own: with the diode current it
  would let GPIO27 rise to about 0.7 V and EN to about 1.3 V, past VENF (the
  AP1606 HD gate of BR-03 has no base-emitter junction to clamp GPIO27); hence
  the 2.4 kΩ, which draws about 1.4 mA when GPIO27 drives high (the only
  high-state load: the AP1606 gate takes no current), inside the default 4 mA
  drive.

D14 also asked for a regulator power-good term; the TPS61022 has no PG pin, so
D15 replaces it with the PINIO instead of adding a supervisor IC: the FC drives
GPIO27 high only after it has booted on a good +5V, GPIO27 sits low through
reset, and the cell threshold sheds the O4 while the boost still has margin
(1.67 A at 2.8 V against the 1.43-1.48 A HD load).
Round 2's Schottky OR with an AP1606 on the boost EN is dropped: the Schottky's
reverse leakage (IR 15 µA typ / 50 µA max at 5 V and 25 °C, about 1 mA at
85 °C; V, Nexperia PMEG2010AEH Table 7 and Fig. 2) into the 100 kΩ gate
pull-down turned the sense FET on in battery-only operation and shut the boost
down whenever the board was warm. The TPS61022 EN is now tied straight to VIN
(`+BATT`; D52 BR-11 deletes round 4's 100 kΩ pull-up): EN and VIN share the
−0.3..7 V absolute maximum (VEN_H ≤ 1.2 V, VEN_L 0.35-0.45 V, V Table 6.5), and
nothing else touches it.

**Setpoint.** TPS61022 VFB is 585/600/615 mV in PWM (±2.5 %, V Table 6.5); with
1 % divider resistors a 5.00 V nominal can sit at 4.80 V, below the rank-1 gate.
The nominal is set to **5.15 V**: worst case 4.93-5.37 V at the boost (I).
Divider (D52 BR-23): **47 kΩ / 6.2 kΩ** (Yageo RC0201FR-0747KL /
RC0201FR-076K2L), 0.600 V x (1 + 47/6.2) = 5.148 V, the same window as round
4's 909k / 120k; TI asks for a bottom resistor below 300 kΩ, and the lower
impedance improves noise immunity at the FB pin. The
mux adds 37-60 mΩ (V): 0.04 V at the analog load, 0.06-0.10 V at the HD load, so
+5V stays ≥ 4.89 V (analog, the 4.85 V gate holds with the ripple trough) and
≥ 4.83 V (HD, gate 4.75 V); the maximum stays inside the LP5912 (6.5 V; the
TLV75533 fallback 5.5 V), TPS2116 (5.5 V operating), TPS22810 (18 V) and the
SE5004L on the +5V selector position (5.5 V).

**Inductor saturation and overload.** The TPS61022 limits the inductor
**valley** current (6.5 min / 8 typ / 10 max A, V Table 6.5), not its peak. Up
to the published loads the peak stays at or below 80 % of the 6.5 A Isat (5.2 A
worst case at 1.7 A from 2.8 V with −30 % inductance, I). In current limit the
peak is the valley limit plus the ripple, 9.5-13 A, which the
FTC252012SR68MBCA does not carry: as a metal-alloy molded part it saturates
softly (S), so its inductance falls, the ripple and the low-side FET current
grow, and only thermal shutdown (150 °C) ends it (I). TI's recommended
inductors are rated 11.5-28 A (V Table 8-2) and none comes near 2520. Hard
shorts are covered by the output short protection (current folds back below
VOUT 1.8 V to about 0.7 A at < 0.4 V, V §7.3.7). The exposure is an overload
between about 2 A and current limit with VOUT above 1.8 V, from a user-pad fault
or an O4 inrush; the TPS22810 slew (CT 10 nF: about 4.7 V/ms, V Eq. 3) keeps
the inrush to about C x 4.7 V/ms (0.2 A per 47 µF; the O4's input capacitance is
not published, V1). V1 adds an overload step to 2.5 A at 2.8 V for 10 s and a
short on the user 5V pad. Fallback if V1 fails: Coilcraft XGL4040-681 (0.68 µH,
Isat 8 A at 20 % drop, 4 x 4 x 4 mm, S; +10 mm² bottom).

Options weighed:

| Question | Options | Decision | Why (numbers) |
|---|---|---|---|
| 5 V converter | TPS61023 (SOT-563, 2.7 A valley, auto-PFM), TPS61022 (2x2, 6.5 A valley, forced-PWM pin), TPS63070 buck-boost, SY7088 (3 A peak) | **TPS61022RWUR + 0.68 µH 2520, 4 Cout (D15)** | Forced PWM keeps the 1 MHz ripple fixed and out of the PFM range that shows as video bars. Calculated per TI §8.2.2.2 (inductance −30 % = 0.48 µH, peak at 80 % of Isat 6.5 A, η 0.85 / 0.86 / 0.87 at 2.8 / 3.0 / 3.2 V, I from TI's curves at 1.5-2 A): **1.67 / 1.82 / 1.98 A**, against 0.70 A analog and 1.43-1.48 A HD (§5.1); ripple is 159 % of the inductor DC current at the analog load (TI asks ≤ 40 % at full load) and the −20 % tolerance part stays above TI's 0.33 µH floor. Above 1.5 A the datasheet needs ≥ 20 µF effective Cout: four X6S 0603 give about 20-28 µF at 5.15 V. Binding limit: TJ ≤ 125 °C (recommended operating, V §6.3), not the 150 °C shutdown: at the HD load from 3.0 V about 1.2-1.3 W of loss, 1.0-1.1 W in the IC, +37-40 K by ΨJB 36.7 K/W (V), so TJ 85-99 °C in HD hover (board 48-59 °C at h 80-55, `thermal_v3.py`) and 125 °C only on an 85-88 °C local board. The 2 mm boost-to-FET distance is a D69 preference (§5.3, bom_plan U2), traded for density where needed; a loaded ESC quarter next to it adds to its TJ (V1 logs the case temperature). The TPS63070 (D14's alternative) gives 1.49-1.65 A at 2.8-3.0 V and is weaker at 1S (study, D15) |
| 3.3 V supply path | 5 V boost + LDOs (as drawn) vs a cell-fed 3.6 V buck-boost (TPS63802 class, S) with post-LDOs | **as drawn**; heat lever (b) in §5.4 | All 3.3 V loads through boost + LDO cost about 0.65 W of overhead for 0.96 W delivered. A 3.6 V buck-boost would save about 0.45 W for 15-20 mm² on the bottom, which the bottom does not have (§9) |
| PA supply | 5 V boost + load switch (track 06 R6) vs cell (track 04) | **Cell (+BATT)**, 3-pad 0 Ω selector to +5V (D54: kept until V5, fixed +BATT copper for production) | SE5004L is rated 3.0-5.5 V; takes 0.3-0.55 A off the boost; VREF low = 0.5 µA so no load switch; on USB only the PA has no supply. The selector is a 3-pad land with one 0402 0 Ω fitted between the centre and one side: a solder blob across a 3-pad solder jumper would short the boost output to the cell, a single 0402 cannot bridge both sides; the unfitted pad 3 carries no paste (a stencil deposit 0.40 mm from pad 2 could bridge +5V to PA_VCC in reflow; the 2-3 rework is hand-soldered). Below 3.0 V cell the PA is out of rating (V5 measures at 2.8 V). Bench test V5 decides (§14) |
| USB / boost source | Schottky OR + boost EN held off on USB (round 2); USB load switch with reverse-current blocking + boost held off on USB; 2:1 mux with the boost always on | **TPS2116 mux, boost always on** | the Schottky's reverse leakage defeats the USB sense in battery-only operation (above); a blocking switch with the boost held off drops +5V for the 0.7 ms soft start on every USB unplug; the mux switches in about 8 µs onto a running boost |
| 3.3 V rails | one LDO for all (about 0.29 A: 0.49 W, +82 K in X2SON) vs split | **FC and RX on one LP5912 (WSON-6), the RTC6705 on its own LP5912, + gyro LDO + PA reference** (D14 regulator consolidation; round 2 had a separate RX rail) | In flight the RX takes up to 0.16 A and FC + RX is 0.20-0.25 A, 0.37-0.46 W in WSON-6 (RθJA 71.2 K/W on a JEDEC board, V: +26-33 K); the ELRS Wi-Fi mode restored by D58 (bench only, disarmed) peaks at about 0.48 A on +3V3 (root power table), inside the LP5912 500 mA rating. The RTC6705 keeps its own rail for the VCO and for the D17 hold-off. Saves the TLV75533 and two caps (2.8 mm² bottom) |
| ESC MCU supply | VBAT direct vs 3.3/5 V rail | **VBAT direct**, each EFM8 on its own cluster's +BATT, 100 nF X6S at the pin; the 1 µF-class bulk is the slot-M hot-loop cap (one of three 10 µF X6S 0402 per ESC, D77) within 4 mm of VDD pin 4 through the +BATT plane (BR-05 as amended; C30 deleted, D77; P5 check `check_p5_conditions.py`), no series R | EFM8BB51 VDD 1.8-5.5 V (V); gate drive = cell voltage; motors survive a BEC fault. A series R (10 Ω x 1.1 µF) would leave most of the PWM ripple between P source and P gate; tied directly, VDD tracks the P sources (track 03 §8: at most 2.2-4.7 Ω). VDD peak and logic-high margin: §4.4 |
| USB ESD | 2-line ESD array at the connector vs none | **TI TPD2EUSB30 at J31 (D57)** | owner D57 puts D+/D− ESD on the board with the JST SH plug: 0.7 pF, IEC 61000-4-2 8 kV contact, VRWM 5.5 V and 6 V IO abs max, so a D+/D− short to VBUS survives; ahead of the 27 Ω series resistors. The round-4 'none' (house practice) is superseded |
| USB VBUS hot plug (round 4) | nothing on `+5V_USB` but the PR1 divider (round 3); VIN1 capacitor; board TVS; damping at the cable end | **SGM40661 OVP load switch on VBUS (D57: 28 V abs max at IN, trips at 5.75-6.12 V in 80 ns, 15 ms debounce, 2 ms soft turn-on; simulated cable ring ≤ 10.8 V at its IN, never at VIN1) + 10 µF X6S 0402 at VIN1** (the clip-on adapter of O3 is gone; text below is the round-4 analysis) | With the cell fitted the USB channel stays open until VBUS reaches +5V, so VIN1 is almost unloaded, and a cable's 0.5-1 µH can ring it toward twice VBUS on plug-in or pogo bounce, past the 6 V absolute maximum of VIN1, MODE and PR1 (V, SLVSFG1A §6.1); a failed mux takes +5V, the FC, RX and VTX down. The house OpenFC-Lite-Mini feeds VBUS into a 40 V DSK24 Schottky with 22 µF behind it (V, netlist); here a 6 V CMOS mux sits on the pad, so the house "no array" argument does not carry over. A board TVS would not protect it: 5 V parts break down at 6.4-7.5 V (SMF5.0A 6.40 V, TI TVS0500 7.5 V minimum; V), above 6 V. The VIN1 ceramic meets TI's "CIN of 1 µF is sufficient" (§9) and the layout rule (§10), but it also forms the LC with the cable, so the damping goes at the cable end: the adapter carries a 5 V VBUS TVS and a damped bulk (10 µF ceramic in series with about 1 Ω, or a polymer part with ESR near √(L/C)), sized with the board's VIN1 part (10 µF nominal, about 2.5-3.5 µF effective at 5 V, I) inside USB's 10 µF attach limit (O3, P4-3). Behind the adapter, the pogo contacts (a few nH, 30-100 mΩ each) leave ζ about 0.4-1.5 at VIN1 (I). V1 scopes VIN1 through the adapter, pass ≤ 6.0 V; board fallback: an RC snubber (1 Ω 0201 + 4.7 µF 0402) at the pogo +5V pad, +2.3 mm² bottom |

On USB only: the bench loads are FC 0.09 A, RX 0.10 A, RTC6705 0.10 A and the
camera 0.12 A at 5 V: 0.42 A. The mux drops 0.02 V there (V), so +5V is VBUS
less the adapter and cable drop, about 4.6-5.2 V (I), with ample LDO headroom;
below VBUS 3.44-4.04 V (3.37-4.10 V with 1 % R) the mux stops selecting USB. With the battery fitted as
well, +5V still runs from USB and the boost idles; the PA and the motors run
from the cell, and so does the O4 when the HD line is on (its switch sits on
`+5V_BST`, BR-10). The OSD needs a camera on the bench (§4.5).
Bidirectional DShot idles high on USB and back-feeds the unpowered EFM8s and
+BATT through the 2.4 kΩ resistors; PINMAP §4.5 documents that case and V9
tests it.

Parts:

| Function | Primary (MPN, maker, package, stock) | Fallback | Reuse |
|---|---|---|---|
| Boost | TI **TPS61022RWUR**, VQFN-HR-7 2x2, C915088, 857 | TI TPS61023DRLR, SOT-563, C919459, 53,320 (new land, 1.6 A at 2.8 V) | new |
| Boost inductor | cjiang **FTC252012SR68MBCA**, 0.68 µH, 2.5x2.0x1.2, Isat 6.5 A, 17 mΩ, C5832369, 6,040 (V, LCSC parameters) | Coilcraft XGL4040-681, Isat 8 A at 20 % drop, 4x4x4 (S), if the V1 overload step fails; cjiang FTC252012S1R0MBCA (1.0 µH, Isat 5.6 A, C5832370) is not a fallback any more (1.71 A at 3.0 V) | new |
| Boost caps | Cin 1x, Cout 4x (D15) Murata **GRM188C80J226ME15D** 22 µF 6.3 V X6S 0603, C393031, 104,510 | a 10 V X6S/X7R 22 µF 0603 found in P3 (better DC bias) | new |
| USB / boost mux | TI **TPS2116DRLR**, SOT-583 (DRL) 2.1x1.6, 1.6-5.5 V (6 V abs max on VIN1, MODE, PR1), 2.5 A, 40 mΩ typ (≤ 60 mΩ), reverse-current blocking, TA −40..105 °C, C3235557, 77,966 (V) + PR1 divider 27.4k/10k Yageo RC0201FR-07 (threshold 3.44-4.04 V) + VIN1 input capacitor 10 µF 6.3 V X6S 0402 (Murata GRM155C80J106ME11D, D52 BR-20: about 2.5-3.5 µF effective at 5 V against TI's CIN 1 µF, SLVSFG1A §9, I; X6S as the board's one 10 µF line, no distance rule: D69, C30 deleted by D77). Reverse current blocking happens by design at USB plug-in and unplug with a cell fitted; TI §7.3.4 asks for a VOUT clamp or about 100 µF where RCB occurs: considered deviation, no part (lean rule: short +5V copper, near-zero current at the 42-70 mV RCB trip), V1 captures the VIN1 / VOUT spikes (≤ 6.0 V, +3V3 ≥ 3.0 V) | TI TPS2121RUXR, VQFN-HR 2x2.5, 2.8-22 V, C485916 (S; new land) | new |
| O4 load switch (D15, D83) | TI **TPS22810DRVR**, WSON-6 2x2 (DRV0006A, the land of the LP5912-3.3DRVR), 2.7-18 V, 79 mΩ typ (≤ 115 mΩ), 3 A at TA 65 °C, RθJA 74.6 K/W, EN/UVLO VENR 1.13-1.30 / VENF 1.08-1.18 V, CT slew, QOD, TA −40..105 °C (V, SLVSDH0C); TI orderable table: Active, no LCSC listing, NextPCB by MPN (D60); EP to GND as on TI's TPS22810EVM (SLVUAY7B Fig. 1); loss 0.11-0.17 W at 1.2 A, +8-13 K | TI TPS22810DBVR (SOT-23-6, 2 A, 182 K/W, C205990): only if the board stage refuses the WSON, with a logged reason | study; package D83 (P4 critique r4: smallest-package rule; the DBV had been kept only for stock, which D60 removed) |
| O4 EN parts | +BATT divider 33k/18k + 510 kΩ hysteresis from +5V_HD (Yageo RC0201FR-0733KL / -0718KL / -07510KL, D53 BR-22; on at 3.23-3.82 V rising, shed at 2.74-3.14 V falling with 1 % resistors, set at V1) + 100 nF EN filter (GRM033C81E104KE14D, τ 1.1 ms); Nexperia **BAS16LD,315** PN switching diode, SOD882D 1.0 x 0.6 (PINIO1, pull-down only; IR ≤ 30 nA at 25 V / 25 °C; V datasheet Rev. 1; LCSC C841775, about 900, and Farnell / RS listings, S: O17 confirms) + 2.4 kΩ 0201 pull-down on GPIO27 (Ralec RTT012401FTH, BR-24); CT 10 nF 0201 X7R (GRM033R71A103KA01D, BR-19); no separate CIN (C17 deleted, D79: the boost outputs C8-C11 serve under the P5 condition 'U5 VIN within 3 mm of C8-C11 or U3 VIN2'); no USB term (the round-4 AP1606 is deleted, BR-10) | Nexperia BAS116 class low-leakage diode (S, larger package); not a Schottky (§4.2) | study; diode changed in consolidation; filter and hysteresis added in round 4 (TI SLVSDH0C §9.3.3); values and supply node D53 |
| +3V3 LDO (FC + RX, D14) | TI **LP5912-3.3DRVR**, WSON-6 2x2, C524780, 23,490 [PU]; CIN shared with the +3V3_VTX LDO: one Murata GRM155C80J106ME11D 10 µF X6S 0402 between the two IN pins, 2.4 mm apart (D52 BR-14, replaces 2x 1 µF 0201 that sat below the > 0.5 µF effective minimum and in an X5R H1 breach). COUT: the +3V3 sum falls from about 31 to about 19 µF nominal (9-10 µF effective, I) after D52, still at the LP5912 10 µF maximum: P4 sums it with maker curves (§15.5 P4-12) | TI TLV75533PDQNR (X2SON-4 1x1, C2861882, 2,025 [PU]) as a separate FC rail (round-2 split, +2.8 mm²) | OpenFC `power` back end |
| +3V3_VTX LDO | TI **LP5912-3.3DRVR** (D12: the part already on the BOM); also feeds the PA reference and the PNP drive stage after D52 (BR-02, BR-03): COUT 16.0 µF nominal, about 6.8 µF effective at 3.3 V (5.4-8.2 µF at ±20 %, VTX sheet), inside the LP5912 0.7-10 µF window | TI TPS7A2033PDQNR, X2SON-4 1x1 (commons-verified; LCSC 0 on 2026-10-07), −3.8 mm² once a NextPCB channel shows stock | BOM reuse |
| PA VREF reference | TI **LP5907SNX-2.85/NOPB**, X2SON-4 1x1, 2.85 V ±2 % (2.79-2.91 V, just outside the SE5004L's 2.80-2.90 V at both corners; S, maker listing via Arrow): V5 qualifies Icq and gain at 2.79 and 2.91 V (§4.8). VIN on `+3V3_VTX` (D53 BR-03); COUT Samsung **CL05A475MP5NRNC** 4.7 µF 0402 (BR-26: the 0201 1 µF was below the > 0.7 µF effective minimum; X5R allowed, 3.1 mm from a FET and 16 mm from the PA); CIN Samsung CL05A475MP5NRNC 4.7 µF 0402 (about 2.6 µF at 3.3 V; LP5907 DS 5.6 / 7.2.2.4: > 0.7 µF effective over all conditions within 1 cm; the 1 µF 0201 at about 0.45 µF missed it and C108 serves the RTC6705, P4 critique r3) | a 2.8 V variant if V5 qualifies a lower VREF (lever (a), §5.4) | new |
| +1V8 gyro LDO | TI **TPS7A2018PDQNRM3**, X2SON-4 1x1, C36996449, 8,090 | TI LP5912-1.8DRVR, WSON-6 2x2, C2876234, 728 [PU] | OpenFC `imu` rule |
| HD gate (D17) | ALLPOWER **AP1606**, DFN-3L 1.0x0.6 (D53 BR-03: drain on the +3V3_VTX LDO EN, gate on HD_EN, source GND; no resistors) [PU] | - | BOM reuse (beeper FET line) |
| RP2354A core inductor | Abracon **AOTA-B201610S3R3-101-T**, 3.3 µH 2016, C42411119, 625 [PU] | external 1.1 V LDO with the SMPS bypassed (RPi guide option) | OpenFC `rp2350a` |
| Camera ferrite | Murata **BLM03PX121SN1D**, 0201, 0.9 A, 160 mΩ, −55..125 °C (S: Digi-Key/Element14 listings; TME 5,024 on 2026-10-07) | Murata BLM03PX220SN1D, 0201, 1.45 A (S) | commons |
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

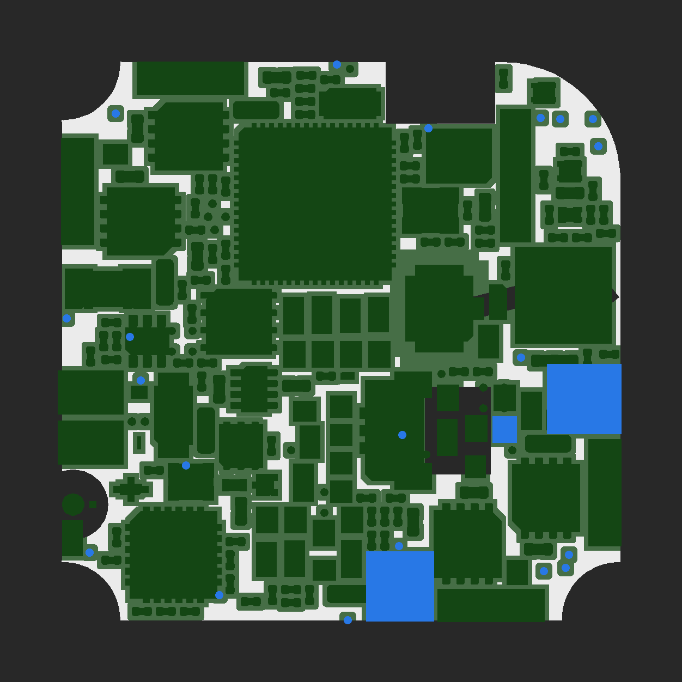
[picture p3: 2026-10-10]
images/floorplan-empty-top.png

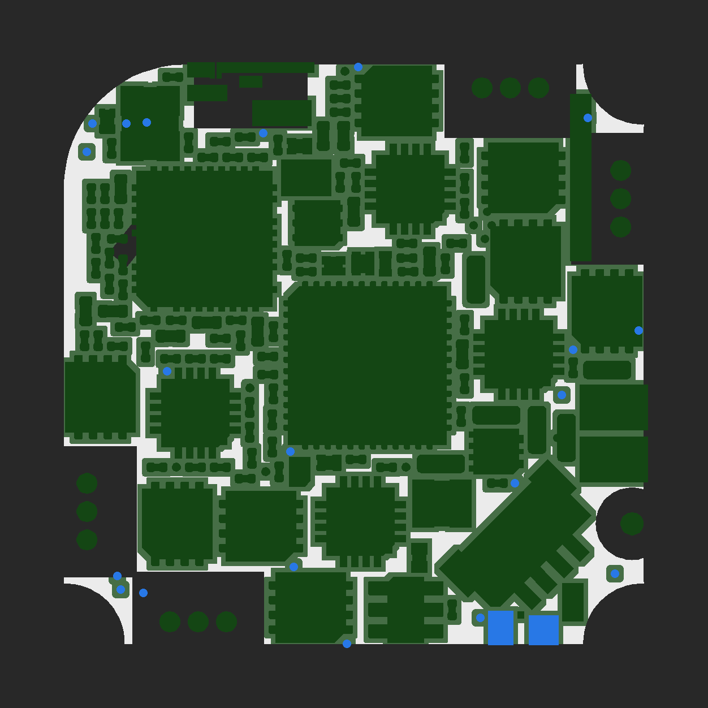
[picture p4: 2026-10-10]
images/floorplan-empty-bottom.png

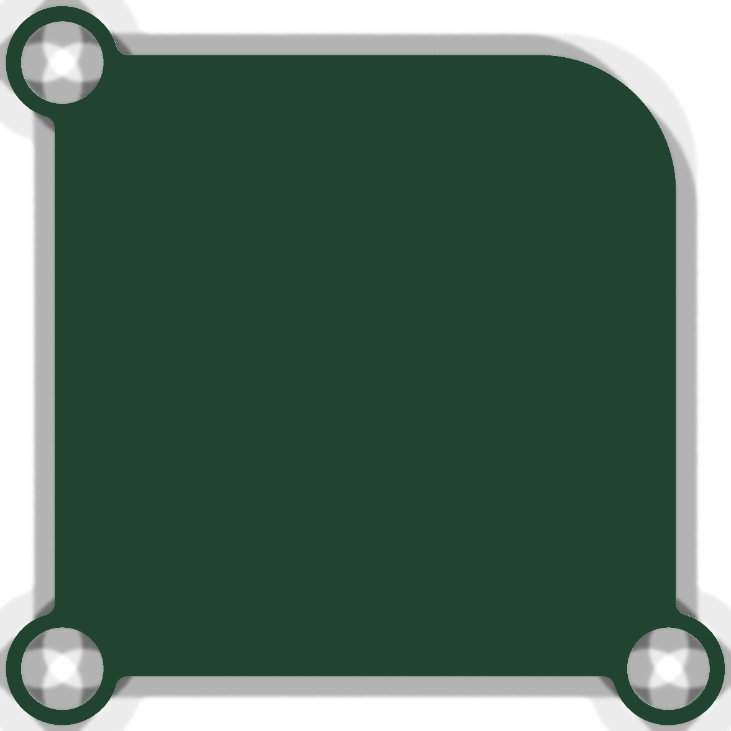
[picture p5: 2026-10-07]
images/p1-outline-top.png

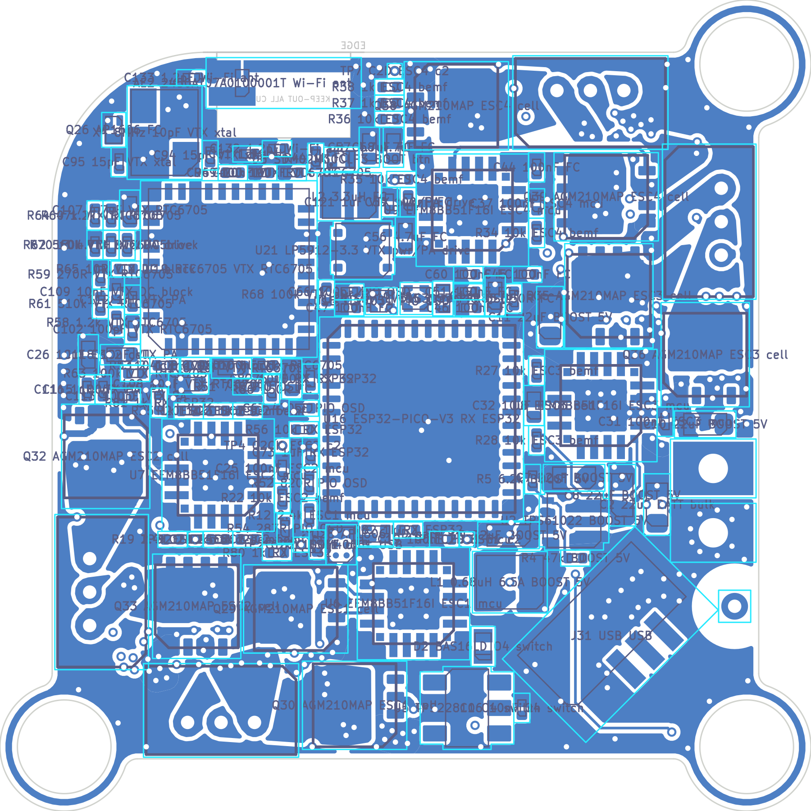
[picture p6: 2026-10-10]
images/review/copper-bottom.png

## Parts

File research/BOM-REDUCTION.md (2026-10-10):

# OpenAIO-Whoop BOM reduction: integrated decision list

Date 2026-10-09. Read-only integration of four verified track reports. No repo file was edited.

**Track reports (each with its own Verification section):**
- `bomred/rx-vtx.md` (RV-xx): RX MCU, flash, radio, VTX control.
- `bomred/passives.md` (PS-xx): passive standardisation and lean decoupling.
- `bomred/power-esc.md` (PE-xx): power tree and ESC cells.
- `bomred/vtx-fc-misc.md` (V-xx, F-xx): VTX chain, FC support parts, misc.

Only proposals that survived verification are listed. Amendments from the verification passes are already applied
(corrected MPNs, corrected counts, corrected model numbers).

**Method.** `bomred/integ/integrate.py` and `bomred/integ/final_order.py` apply every proposal to
`hardware/bom_plan.json` and recount. Sides come from the placed floorplan (`hardware/floorplan.json`). Land extents
come from the P2 kernel (`p23/fp/work/fpinfo.json`). Numbers are in `bomred/integ/totals.json`.
- **Placements** = BOM placements (assembled parts). Pads, test points, logo and the antenna hole are out of the BOM.
- **Lines** = unique manufacturer part numbers (MPNs) in the BOM.
- **Area** uses the FLOORPLAN.md metric: land extent plus a 0.1 mm halo per side ("occupied"). Deltas come from the
  land extents and are added to the measured P2 baseline. Negative = saved. F = top, B = bottom.

**Labels.** V = verified from a primary source in the track reports, S = screened (distributor), I = inferred in
this integration.

---

## 0. The owner's question

> "I see an ESP with external flash? Look at OpenRX-Lite-UFL."

- **Yes.** The RX uses an ESP32-D0WD-V3 with an external GD25Q32EEIGR flash and an external 40 MHz crystal.
- The plan also missed a capacitor the ESP32 needs: CAP1, 10 nF, which Espressif calls "required for proper
  operation".
- **OpenRX-Lite-UFL cannot be reused as is.** It uses an ESP32-C3FH4 (in-package flash) with an SX1281, but on
  ExpressLRS (ELRS) 4.x the C3 cannot drive the VTX:
  - `rx_main.cpp` l. 91-95 compiles the VTX SPI device out on the C3 (V);
  - the C3 has a single general-purpose SPI;
  - it would use 15 of 15 usable GPIO.
- **The FC cannot take the VTX either.** Betaflight on the RP2350 has `#undef USE_VTX_RTC6705` (V), and the FC has
  no spare GPIO.
- **The in-package-flash part that works is the ESP32-PICO-V3 (BR-01).** It holds the flash, the 40 MHz crystal,
  the CAP network and most bypass capacitors inside the package.
  - It saves 12 placements.
  - It runs the stock `Unified_ESP32_2400_RX` build, with its own layout JSON.
  - With BR-06 and BR-25, the RX block goes from **32 to 19 placements**.
- **Board-wide, the "apply now" set is −41 placements and −13 lines** against the corrected baseline.

---

## 1. Totals

| | Plan (`bom_plan.json`, placed P2 board) | Corrected baseline (§2) | **After "apply now" (BR-01 to BR-26)** | "Apply now" without BR-01 (RX fallback) | "Apply now" + owner calls OC-1 to OC-3 |
|---|---|---|---|---|---|
| BOM placements | 282 (F 125 / B 157) | 286 (F 125 / B 161) | **245 (F 110 / B 135)** | 256 (F 110 / B 146) | 229 |
| of which passives | 218 | 222 | 185 | 194 | 181 |
| Unique BOM lines | 88 | 89 | **76** | 78 | 73 |
| Footprints incl. pads, test points, logo | 326 | 330 | 289 | 300 | 273 |
| Top, occupied incl. halo (usable 628.5 mm²) | 445.6 mm² (70.9 %) | 445.6 (70.9 %) | **434.3 (69.1 %)** | 434.3 (69.1 %) | 431.2 (68.6 %) + OC-1 P2 rerun |
| Bottom, occupied incl. halo (usable 616.6 mm²) | 457.5 mm² (74.2 %) | 460.6 (74.7 %) | **459.9 (74.6 %)** | 448.7 (72.8 %) | 459.2 (74.5 %) + OC-1 P2 rerun |
| Top, package only | 313.0 mm² (49.8 %) | 313.0 (49.8 %) | 306.4 (48.8 %) | 306.4 (48.8 %) | - |
| Bottom, package only | 328.0 mm² (53.2 %) | 329.8 (53.5 %) | 337.6 (54.7 %) | 322.7 (52.3 %) | - |

**Deltas of the "apply now" set**

| Against | Placements | Lines | Area, occupied incl. halo |
|---|---|---|---|
| Corrected baseline | **−41** | **−13** | **F −11.3 mm², B −0.7 mm²** |
| Plan | −37 | −12 | F −11.3, B +2.4 |

The bottom stays level because BR-01 adds 10.6 mm² there. The rest of the set frees 11.3 mm² on the bottom.

**Variants**

| Variant | Placements | Lines | Top | Bottom |
|---|---|---|---|---|
| BR-05 22 µF caps moved to the top (likely, §3 note) | 245 | 76 | 441.2 (70.2 %) | 453.0 (73.5 %) |
| BR-02 falls back to PS-12 | 248 | 76 | 436.8 (69.5 %) | unchanged |
| Worst case: BR-01 fails, BR-02 falls back, BR-17 kept | 260 | 78 | 437.4 (69.6 %) | 448.7 (72.8 %) |

The worst case is still −26 placements and −11 lines against the corrected baseline.

**Per block (plan → after)**

| Block | Plan | After |
|---|---|---|
| RX | 32 | 19 |
| VTX | 70 | 58 |
| Power | 38 | 34 (+3 corrected-baseline parts kept) |
| ESC | 20 per cell | 19 per cell (ESC3 stays at 20) |
| FC | 32 | 30 |
| IMU | 7 | 5 |
| OSD | 13 | 12 |
| LED | 7 | 4 |

---

## 2. Corrected baseline: defects, not savings

These parts are added before any saving is counted. They are not on the placed board yet.

| Item | Parts / lines | Area | Evidence |
|---|---|---|---|
| ESP32 CAP1 10 nF, pin 48 to GND, X7R ±10 % (PS-00). Only CAP1: the CAP1-CAP2 RC (RV-0a) "is not required" without Deep-sleep, and ELRS never sleeps (Espressif schematic checklist, V) | +1 / 0 | B +0.66 | ESP32 DS v5.3 Table 2-1; checklist "required for proper operation". Moot with BR-01 |
| D24 TPS2116 VIN1 capacitor | +1 / 0 | B +1.13 | spec §4.2; BR-20 sets the MPN |
| D34 O4 EN 1.5 MΩ hysteresis resistor | +1 / +1 | B +0.66 | DECISIONS D34; BR-22 sets the values |
| D34 O4 EN 100 nF filter | +1 / 0 | B +0.66 | DECISIONS D34 |
| R9 80.6k → 90.9k (D34; plan stale) | 0 / 0 | 0 | spec §4.2 |
| **Total** | **+4 / +1** | **B +3.1** | 286 placements, 89 lines |

Other baseline defects, all fixed inside the set:

| Defect | Fixed by |
|---|---|
| PA drive stage cannot turn Q1 on: Vb = 0.119 x V_PWM (PS F-A, V) | BR-02, or PS-12 if BR-02 falls back |
| LP5912 input capacitors below their effective minimum (F-D) | BR-14 |
| LP5907 output capacitor below its effective minimum (F-C) | BR-26 |
| U17 85 °C flash inside the PA shadow (RV-0b) | BR-01 removes U17; fallback §5 |

---

## 3. Apply now (no function loss, verified), ranked

**Column guide**
- **Parts** and **area** are additive.
- **Lines alone** = the proposal on its own against the corrected baseline.
- **Lines in order** = incremental in this rank order. That column sums to the total (−13).
- Area is in mm², occupied metric, F / B.

### 3.1 Placement savings

| Rank / ID | Source (verdict) | Change, exact MPNs | Parts | Lines alone / in order | Area F / B | Risk, gate |
|---|---|---|---|---|---|---|
| **BR-01** | RV-4 (confirmed, with correction); includes PS-09, PS-00 CAP1, RV-0a, RV-0b | Espressif ESP32-D0WD-V3 (U16), GigaDevice GD25Q32EEIGR (U17), CJ17-400001010B20 40 MHz (X2), C71/C72 GRM0335C1H150JA01D, C80 GRM033R61A105ME44D, C81/C74/C75/C78/C79 GRM033R61E104KE14D, C77 GRM033R61A103KA01J and CAP1 → **Espressif ESP32-PICO-V3** (LCSC C967022; alternate ESP32-PICO-V3-02). Keep C76 100 nF, C82 10 µF, R56/C73 (CHIP_PU RC), R57 (LNA_IN dummy) | **−12** (−11 vs plan) | −2 / −2 | 0 / **+10.6** | **Medium. Gate: a P2 placement trial.** The PICO is −40..85 °C (in-package flash), so under rule H3 it must sit ≥ 2 mm outside the PA projection (bottom keep-out x 4.32..12.72, y −13.4..−5.0 mm) and ≥ 2 mm from the FET groups, with check_spacing at 0. It needs its own ELRS layout JSON (§6 item 1) and a new P3 footprint and symbol. Stock: LCSC 335, DigiKey 4,812; HQ Online lists only V3-02 (443). Confirm the bootloader's handling of the in-package flash pins at V1 bring-up (I) |
| **BR-02** | V2 (confirmed; model corrected); supersedes PS-12 | Q27 Nexperia BC847QASZ, R71/R72 RC0201FR-0718KL, R73 RC0201FR-0710KL, R74 RC0201FR-076K2L, R75 RC0201FR-07150RL, R76 RC0201FR-071KL, R77 RC0201FR-073K3L, C124/C125 GRM033R61E104KE14D → **Nexperia BC857BM,315** PNP (emitter through Re to +3V3_VTX, collector to R65 → L3 → PAOUT1), 2-pole RC 2x RC0201FR-071KL + 2x GRM033R61A105ME44D, Re RC0201FR-0710RL. `vtx_amp_pwm` moves to ESP32 GPIO13 by target overlay | **−4** | −2 / −2 | **−3.2** / 0 | **Medium. Gate: P4 SPICE before schematic freeze, then V5/V8.** PAOUT1 is driven in current mode, and the RTC6705 gives that current as "TBD". Corrected model: YOLO ceiling 26-30 mA at Re 27 Ω, 49-66 mA at 10 Ω; pinch-off at ≥ 3400 counts; about 255 duty steps. Start Re at 10-15 Ω. Fixes PS F-A |
| **BR-03** | V1 (confirmed) | Q28 BC847QASZ → **ALLPOWER AP1606** (drain VTX_PWR_EN, gate HD_EN, source GND). TI LP5907SNX-2.85/NOPB (U22) VIN moves from +3V3 to **+3V3_VTX**. Delete R78/R79 RC0201FR-0710KL and R83 RC0201FR-071KL | **−3** | 0 / −1 (BC847QASZ line goes with BR-02) | 0 / −2.5 | Low. In HD mode the LDO collapse also removes PA_VREF. LP5907 VEN is rated −0.3..6 V to GND, so GPIO2 needs no series resistor. V9 adds a check for PA_VREF < 0.5 V in HD mode. See §6 item 9 for the LP5907 input |
| **BR-04** | F1 (confirmed) | Delete Nexperia 74LVC1T45GS,132 (U23) + C126/C127 GRM033R61E104KE14D. RP2350 GPIO8 drives the LED pad directly, with no series R, like the other user pads | **−3** | −1 / −1 | 0 / −3.0 | Low-moderate. A WS2812 at 5.15 V wants VIH 3.6 V. Add the Betaflight inline-diode note to the README; V9 tests a strip. Matrix II parity (`LED_STRIP_PIN PB2`, direct, V) |
| **BR-05** | PE-7 (partly refuted: −3, not −4) | Delete the EFM8 VDD 2.2 µF caps C18, C24, C36 (Murata GRM155C81A225KE11D, ESC1/2/4). Each cell's 22 µF GRM188C80J226ME15D (C23, C29, C41) moves ≤ 3 mm from EFM8 VDD pin 4. The 100 nF at the pin stays. ESC3 keeps C30 (gyro 5 mm bulk-MLCC rule) | **−3** | 0 / 0 | −3.4 / 0 | Medium-low. P5 must find the 0603 sites. The bottom under the EFM8s is taken, so the top variant is likely: F +3.5, B −6.9 instead. Bus capacitance drops 3.0-4.2 µF effective, so V3c (hot-plug test) checks it. Do not stack with PE-8 before V3c (§6 item 11) |
| **BR-06** | PS-08 = RV-3 (confirmed) | Delete C90 GRM033R61A103KA01J and C93 GRM155C80J106ME11D at the SX128x. The Semtech Table 15-1 set stays (C86, C87, C88, C89, C91), plus C92 1 µF | **−2** | 0 / 0 | 0 / −1.8 | Low. V7 checks TX droop. This is also the main lever on the LP5912 10 µF output limit |
| **BR-07** | PS-05 = PE-4 (confirmed) | Delete the INA186 common-mode caps C3, C4 (GRM033R61E104KE14D). Keep R2/R3 1k + C5 1 µF differential (80 Hz) and the R47/C60 output RC | **−2** | 0 / 0 | 0 / −1.3 | Low. The ibata_scale check catches any offset. Also removes two X5R parts that sit 0.6-0.75 mm from Q5 (H1) |
| **BR-08** | F2, includes PS-04 (confirmed) | Delete C55 (QSPI_IOVDD pin 54 shares C54 at pin 53) and C53 (ADC_AVDD pin 44 shares C49 at IOVDD pin 45) | **−2** | 0 / 0 | 0 / −1.3 | Low. P5 must put C54 ≤ 1 mm from pin 54: that pin powers the RP2354 in-package flash, and C54 is 2.9 mm away today. C49 goes at pin 44 (RP2350 DS §6.1.5). The house OpenFC-Lite-Mini flies 7 caps for these 9 pins |
| **BR-09** | PS-06 VDDIO half + PE-6 VDD half (both verified halves) | Delete C63 (+1V8 100 nF) and C64 (VDDIO 100 nF), both GRM033R61E104KE14D. C61 (1 µF, TPS7A2018 CIN) goes between U12 IN and BMI270 VDDIO pin 5. C62 (1 µF, TPS7A2018 COUT) goes at BMI270 VDD pin 8 | **−2** | 0 / 0 | −1.3 / 0 | Low. As placed, C62 lands about 3.4 mm from U12 OUT: a D33 MINOR, since the about 20 mΩ trace is under the 100 mΩ ESR limit. P5 rotates U12 so OUT faces pin 8 where it can. The gyro noise V-test stays |
| **BR-10** | PE-1 (confirmed) | TI TPS22810DBVR (U5) VIN moves from +5V to **+5V_BST** (TPS2116 VIN2 node). Delete Q1 AP1606 (the USB term of the O4 enable). C17 stays, re-netted to +5V_BST, because PE-2 was refuted | **−1** | 0 / 0 | 0 / −1.2 | Low. The mux's reverse-current blocking keeps USB off the O4 by topology. V1 checks USB + cell + HD mode. Changes D34. Side benefit: the O4 current no longer crosses the mux (0.05-0.07 W saved) |
| **BR-11** | PS-10 = PE-3 (confirmed) | Delete R6 RC0201FR-07100KL; TPS61022 EN ties to VIN (+BATT) | **−1** | 0 / 0 | 0 / −0.7 | None. EN and VIN share the −0.3..7 V absolute maximum |
| **BR-12** | PS-11 (confirmed) | Delete R69 RC0201FR-0710KL (PA_EN pull-down) | **−1** | 0 / 0 | −0.7 / 0 | Low. LP5907 EN has an internal 1 MΩ pull-down, GPIO2 has a 45 kΩ strap pull-down, and ELRS drives the pin low at init |
| **BR-13** | PS-07 (confirmed) | Delete C69. Move C70 (100 nF) to the bottom between U14 SN74LVC1G3157DTBR and U15 TLV7031DPWR (2.5 mm apart) | **−1** | 0 / 0 | −1.3 / +0.7 | Low. Needs the X6S part from BR-18, because the shared cap sits over an ESC quarter |
| **BR-14** | PS-18 amended = PE-5 | Replace C13 + C120 (2x GRM033R61A105ME44D) with one **Murata GRM155C80J106ME11D** (10 µF X6S 0402) between the U4 and U21 LP5912 IN pins (2.4 mm apart) | **−1** | 0 / 0 | 0 / −0.2 | Low. Fixes the LP5912 CIN effective minimum (> 0.5 µF) and an X5R H1 breach next to Q9/Q10 |
| **BR-15** | V4 (confirmed) | Delete C97 GRM033R61E104KE14D (RTC6705 REG1D8, pin 26), as on OpenOSD-X v1.01 C27 "(DNI)". REG1D8_1 keeps C96 470 nF | **−1** | 0 / 0 | −0.7 / 0 | Low-moderate. V5 checks video SNR |
| **BR-16** | V3 (confirmed) | RTC6705 pin 17 (AVDD_6.5, audio VCO) becomes no-connect like pin 13. Delete C99 GRM033R61E104KE14D | **−1** | 0 / 0 | −0.7 / 0 | Low-moderate. This rests on the reference only: OpenOSD-X puts 3.3k + 1 µF to GND on pin 17, not 3.3 V, while the datasheet labels it "Supply IN 3.3 V". V5 checks for no 6.5 MHz spur. Correct spec §4.8 / §16 |
| **BR-17** | V5 (confirmed, conditional) | Delete C119 GRM0335C1H100JA01D (PA output DC block). The SE5004L RFOUT has an internal DC shunt; only RFin is marked "DC block required" | **−1** | 0 / 0 | −0.7 / 0 | Low. **Gate: decided at P4 from the datasheet plus EM** (no DNP footprint is allowed on the RF line). A 10 pF 0201 at 5.8 GHz is above its self-resonance |

### 3.2 Line merges and fixes (0 placements)

| Rank / ID | Source (verdict) | Change, exact MPNs | Parts | Lines alone / in order | Area F / B | Risk, gate |
|---|---|---|---|---|---|---|
| **BR-18** | PS-01 = PE-11 (confirmed; stock corrected) | Every Murata GRM033R61E104KE14D (X5R) → **Murata GRM033C81E104KE14D** (100 nF 25 V X6S 0201) | 0 | −1 / −1 | 0 | Low. Also clears 13 X5R breaches of the ESC-quarter and PA-zone rules (H1/H3). Stock: LCSC C181047 14,900; element14 27,343. About 50 per board after the set |
| **BR-19** | PS-02 amended (PE-9 rejected) | GRM033R61A103KA01J and GRM033R71C103KA01D (listed by no distributor) → **Murata GRM033R71A103KA01D** (10 nF 10 V X7R) | 0 | −1 / −1 | 0 | None. X7R is needed for C109 (0.91 mm from the PA) and for CAP1 in the fallback. LCSC C76941 408,700; DigiKey 7.37 M |
| **BR-20** | PS-03 amended | Retire Murata GRM155C81A225KE11D. C30 (the EFM8 cap left by BR-05) and the D24 VIN1 cap → **Murata GRM155C80J106ME11D** (10 µF 6.3 V X6S 0402, same land) | 0 | −1 / −1 | 0 | Low. VIN1 must be X6S: U3 is 1.62 mm from FET Q20. **Condition:** the critique must accept a 10 µF EFM8 decoupling cap at ESC3 under the gyro 5 mm bulk-MLCC rule; the rule names pad bulk, ESC local bulk and boost Cin. If not, C30 stays at 2.2 µF and this saves 0 lines |
| **BR-21** | PS-17 (confirmed) | R41 VREG_AVDD RC0201FR-0730RL → **RC0201FR-0727RL** (the USB series line) | 0 | −1 / −1 | 0 | Low. The RC corner moves from 1.03 to 1.25 kHz |
| **BR-22** | PS-15 (confirmed) | O4 EN network: R9 / R10 / hysteresis (D34 values 90.9k / 49.9k / 1.5M) → **RC0201FR-0733KL** 33k (new line) / **RC0201FR-0718KL** 18k / **RC0201FR-07510KL** 510k | 0 | −2 / −1 (BR-02 deletes the other 18k uses) | 0 | Low. Verified: shed at 2.80-3.09 V, on again at 3.27-3.77 V, hysteresis 0.333 V, τ 1.1 ms with the 100 nF filter. Cell drain is 82 µA (spec 30 µA), negligible against a live board. Changes D34 values |
| **BR-23** | PS-13 = PE-12 feedback divider (confirmed) | Boost FB: R4 909k / R5 120k → **RC0201FR-0747KL** 47k / **RC0201FR-076K2L** 6.2k. Output 5.148 V, worst case 4.93-5.37 V, as today | 0 | −2 / −1 (BR-02 deletes R74, so 6.2k becomes R5's own line) | 0 | None. TI: keep R2 < 300 kΩ; a lower value improves noise immunity |
| **BR-24** | PE-10 (confirmed; PS-16 not taken) | R11 HD_EN pull-down RC0201FR-074K7L 4.7k → **Ralec RTT012401FTH** 2.4k (the DShot / OSD line) | 0 | −1 / −1 | 0 | None. BR-03 removes the base currents, so GPIO27 high carries about 1.4 mA. With BR-22 the reset clamp is below the 0.81-0.87 V verified with 3.3k, against VENF 1.08 V minimum; P4 recomputes it once |
| **BR-25** | RV-1 (confirmed) | Semtech SX1280IMLTRT → **Semtech SX1281IMLTRT** (OpenDrone library part). SX1280 stays on the line note as the drop-in alternate | 0 | 0 / 0 | 0 | None. One datasheet and one pinout; ELRS uses no ranging. LCSC 283, cheaper than the SX1280; HQ Online 146 vs none. The spec's pin-5 GND fix applies to the symbol |
| **BR-26** | PS-19 (confirmed, fix) | C123 (LP5907 COUT) 0201 1 µF → **Samsung CL05A475MP5NRNC** 4.7 µF 0402 | 0 | 0 / 0 | +0.5 / 0 | None. Fixes the LP5907 COUT minimum (> 0.7 µF effective). X5R is allowed there: 3.1 mm from Q16 and 16 mm from the PA |
| **Total** | | | **−41** | **−13** | **−11.3 / −0.7** | |

### 3.3 Line choices (§6 item 7)

- **R11.** 3.3k (PS-16) and 2.4k (PE-10) tie at 76 lines. 2.4k is chosen because its line survives any VTX-stage
  outcome.
- **PR1.** The PR1 merges are line-neutral once BR-02 lands:
  - PS-14 (3.3k / 1.2k) is taken only with the PS-12 fallback, where it saves 1 line;
  - PE-12's 49.9k / 18k version collapses because BR-22 removes 49.9k.

### 3.4 Lines

Lines removed (18):
- 74LVC1T45GS,132, BC847QASZ, CJ17-400001010B20, ESP32-D0WD-V3, GD25Q32EEIGR;
- GRM033R61A103KA01J, GRM033R61E104KE14D, GRM033R71C103KA01D, GRM155C81A225KE11D;
- RC0201FR-07120KL, -071M5L, -0730RL, -073K3L, -0749K9L, -074K7L, -07909KL, -0790K9L;
- SX1280IMLTRT.

Lines added (5): BC857BM,315, ESP32-PICO-V3, GRM033R71A103KA01D, RC0201FR-0733KL, SX1281IMLTRT.

---

## 4. Needs owner call (function or parity trade)

Each item is incremental on the "apply now" result.

| ID | Source (verdict) | Change, exact MPNs | Parts | Lines | Area F / B | Trade |
|---|---|---|---|---|---|---|
| **OC-1** | PE-15 (confirmed; track: not for rev1) | 12x TI CSD25310Q2 + 12x TI CSD13202Q2 → **12x AGMSEMI AGM210MAP** (P+N half-bridge, PDFN 3.3x3.3, the Matrix II stage) | **−12** | −1 | About board-neutral (spec §4.3 case b); the side split needs a P2 rerun | **For:** Matrix parity; 20 V N and P with a ±12 V gate, which removes the 12 V N-FET disconnect-surge exposure and the gate exposure to the 9.2 V TVS clamp; hot path 34.1 vs 40.2 mΩ; the CSD25310Q2 is already a consigned line (LCSC C2871649, 659). **Against:** LCSC-only (C7431169, 4,690; 0 at HQ Online), which re-opens D12, D23, D36, D45 and the P2 ESC cell; inconsistent Qg data. The track's advice: rev2, or the rev1 fallback if the CSD25310Q2 consigned buy fails |
| **OC-2** | RV-10 (confirmed; not recommended) | Delete TH1 Murata NCP03XH103F05RL and R70 / R84 RC0201FR-0710KL | −3 | −1 | −1.3 / −0.7 | Loses the O6 patch hooks: PA thermal derate and VTX power-down in pit. Stock ELRS reads no NTC and never drives GPIO21. Keep while O6 stays a release gate |
| **OC-3** | V6 = PS-O3 (no objection) | Delete R67 Yageo RC0402JR-070RL (3-pad PA VCC selector); PA_VCC becomes fixed +BATT copper | −1 | −1 | −1.8 / 0 | Loses the prototype +BATT / +5V comparison at sag. Take it after V5 or for production |
| **OC-4** | F9 (confirmed, with condition) | Delete the TP10 GND test pad (no BOM line) | 0 (−1 pad) | 0 | 0 / about −1.0 + label | Changes FCB recovery. Either FCB moves beside the J30 GND pad, which lies under the clip-on USB adapter ("battery first, hold FCB to J30 GND, release, then clip on USB"), or FCB moves to the top beside a user GND pad, which takes it off the bottom fixture |
| **OC-5** | F9b (no objection) | Delete the SWD pads TP12 / TP13 | 0 (−2 pads) | 0 | 0 / about −2.0 + labels | Loses SWD debug on a young Betaflight port. Rev2 |

OC-1 + OC-2 + OC-3 together: **229 placements, 73 lines**, F −3.1 / B −0.7 mm², plus the OC-1 P2 rerun.

---

## 5. Fallbacks and deferred items (not counted above)

### 5.1 Fallbacks for the gated items

**BR-01 trial fails** (keep the ESP32-D0WD-V3). Then these become mandatory:
- **PS-00 CAP1.** Already in the corrected baseline. It takes the BR-19 X7R part, because U16 sits in the PA
  projection.
- **RV-0b.** Move U17 GD25Q32EEIGR ≥ 2 mm out of the PA projection (west of x 4.3 or south of y −5.0 mm), or use a
  105 °C flash grade.
- **PS-09.** Delete C77 (−1 placement, B −0.7).

Result: **256 placements, 78 lines**, top 434.3 mm² (69.1 %), bottom 448.7 mm² (72.8 %).

**BR-02 fails SPICE.** Then PS-12 is mandatory, because it fixes F-A:
- R71 = R72 = R74 = RC0201FR-073K3L;
- C124 = C125 = GRM033R61A105ME44D;
- R73 omitted;
- R75 = RC0201FR-0775RL.

Add PS-14 (R7 RC0201FR-073K3L, R8 RC0201FR-071K2L) to hold 76 lines.

Result: **248 placements, 76 lines**, top 436.8 mm² (69.5 %).

### 5.2 Deferred to a test or design gate

| Item | Change | Parts / lines | Gate |
|---|---|---|---|
| PE-8 = PS-O2 | Pad bulk C1 / C2 Samsung CL10A226MO7JZNC → Murata GRM188C80J226ME15D | 0 / −1 | **After V3c.** Together with BR-05, the inferred hot-plug peak reaches 5.58-5.64 V against the EFM8 VDD absolute maximum of 5.5 V. It also fixes C2's H1 breach; otherwise P5 moves C2 ≥ 2 mm from Q19 |
| PS-O1 | R54 287R → RC0201FR-07270RL | 0 / −1 | P4-10 / V9 (OSD levels −1 to −5 %) |
| PS-O6 | Delete C92 (1 µF at the SX128x) | −1 / 0, B −0.7 | Only if the +3V3 sum stays above the LP5912 10 µF maximum (§7 item 1) |
| PE-13 | INA186A3IDCKR → INA186A3IYFDR (DSBGA-6) | 0 / 0, B −3.6 (track figure) | Area reserve if the BR-01 trial needs bottom room. 0.4 mm WCSP, surface fan-out only |
| RV-2 (refuted) | 52 MHz crystal instead of the TCXO | −2 / 0 | ELRS SX128x does no frequency correction, and FLRC needs ±20 ppm per link. Re-open only after a V7 hot / cold F500 / F1000 test of a crystal sample |
| PE-16 | Boost Cout 4x 22 µF 0603 → 2x 47 µF 0805 | −2 / +1 | No verified DC-bias curve (P3 search) |

---

## 6. Interactions between proposals

1. **RX choice vs ESP32 pins vs the PA drive pin (BR-01 x BR-02).**
   - The PICO-V3 uses GPIO16, 17, 18 and 23 for its in-package flash (Fig. 8; pins 25, 35, 36, 44, 45 NC, V).
   - So `vtx_mosi` (GPIO18) moves to GPIO14, or GPIO15 (MTDO strap), and the F8 3-wire production reads move with it.
   - `vtx_miso` (GPIO23) is left unset or put on an input-only pin (35/38/39). ELRS never reads it.
     **Superseded by D81:** written as `"vtx_miso": -1` explicitly; an omitted overlay key keeps the stock 23
     (the PICO flash DI), which SPIClass::begin() turns into an input.
   - BR-02 puts `vtx_amp_pwm` on **GPIO13**, which is free and not a strap pin on both MCUs (PINMAP §6: 13/14/16/17
     unused today). The BR-02 pin choice therefore does not depend on the BR-01 trial.
   - GPIO12 (MTDI) is then unconnected. Its internal pull-down holds the 3.3 V-flash strap, so the F18
     eFuse-before-flash order stops mattering.
   - Everything goes into the board's own layout JSON / overlay, which the board needs anyway
     (`ledidx_rgb_vtx`, VPD arrays).
2. **RX choice vs FC pins.** Neither RX option touches the FC.
   - CRSF stays on ESP32 GPIO1/3 to RP2354A GPIO0/1.
   - The FC has no spare GPIO (PINMAP F14), and Betaflight RP2350 compiles out the RTC6705 driver and SPI ELRS. No RX
     or VTX function can move to the FC (RV-7).
   - The C3 route (RV-6) is blocked by ELRS 4.x, not by FC pins.
   - BR-04 keeps the LED pad on RP2350 GPIO8, with no pin change.
3. **BR-01 vs area and H3.**
   - The PICO adds 10.6 mm² on the bottom and cannot reuse the U16 site, which is inside the PA shadow.
   - The rest of the set frees 11.3 mm² on the bottom, in scattered pockets.
   - BR-05's top variant moves another 6.9 mm² off the bottom.
   - PE-13 (−3.6 mm²) is the reserve.
   - The P2 trial must re-plan the bottom front quadrant. Its only H3-free strip holds J30, U3 and X1.
4. **BR-01 vs passives.** BR-01 makes PS-00 CAP1, PS-09 (C77), RV-0a and RV-0b moot. BR-19 still needs X7R for C109.
5. **DFM: the fine-pitch qualification goes away.**
   - BR-02, BR-03 and BR-04 remove all three 0.35 mm-pitch leadless parts (2x BC847QASZ, 74LVC1T45GS).
   - BR-01 replaces the 0.35 mm ESP32-D0WD-V3 with a 0.5 mm part.
   - Together they let the O15 NextPCB fine-pitch engineering query (EQ) and the D43 ganged-mask DRU exception be
     dropped. Without BR-01, only the ESP32 stays in the EQ.
6. **BR-02 x BR-03.**
   - The BC847QASZ line disappears only when both land (counted at BR-03).
   - Both put their loads on +3V3_VTX (the PNP emitter and the LP5907 input). HD mode then removes the VCO, the PA
     reference and the PA drive together, so D17 is intact.
7. **BR-02 vs the value merges.**
   - BR-02 deletes the other uses of 18k, 6.2k and 3.3k.
   - BR-22 and BR-23 then keep 18k and 6.2k alive as single uses, so each saves 1 line in the set instead of 2.
   - The line search over all verified value alternatives (`integrate.py`, 30 combinations per scenario) gives
     76 lines with BR-24 (2.4k) and BR-01, in both drive-stage outcomes once PS-14 is added to the PS-12 fallback.
8. **BR-03 x BR-10 (AP1606).** BR-10 deletes Q1 and BR-03 adds Q28, so the AP1606 line stays at two parts (Q26
   beeper, Q28 HD gate).
9. **BR-03 vs the LP5907 input and the +3V3_VTX rail** (I, this integration).
   - After BR-03, the LP5907 input is C122: 0201 1 µF, about 0.5 µF effective, below the 0.7 µF minimum.
   - The +3V3_VTX bulk C108 (10 µF) sits 6.5 mm from U22 on the same side (floorplan). That is inside the 1 cm
     guidance only if P5 routes +3V3_VTX directly from C108 to U22. Otherwise C122 becomes CL05A475MP5NRNC
     (0 lines, F +0.5).
   - +3V3_VTX also needs a branch of about 10 mm to the top rear-left (U22 + the drive stage), which D33 accepts.
   - The U21 output capacitance rises to about 12.3 µF nominal, about 5-6 µF effective (I). P4 checks it against the
     LP5912 10 µF maximum.
10. **GPIO27 (BR-03, BR-22, BR-24).**
    - With no base currents, the 2.4k pull-down is the only high-state load (about 1.4 mA).
    - The PS-15 clamp was verified at 0.81-0.87 V with 3.3k. A stronger 2.4k pull-down only lowers it.
11. **Hot-plug bus capacitance (BR-05 x BR-20 x PE-8).**
    - BR-05 removes 3.0-4.2 µF effective from +BATT.
    - BR-20 gives back about 1.5-2 µF at C30 (10 µF instead of 2.2 µF X6S) (I).
    - PE-8 would remove another 4-6 µF, so it waits for V3c.
12. **BR-05 x BR-20 x the gyro rule.** C30 must stay at ESC3. If the critique counts a 10 µF there as ESC bulk, C30
    stays at 2.2 µF and BR-20 saves 0 lines.
13. **BR-13 needs BR-18.** The shared OSD cap sits over an ESC quarter, so it needs the X6S part.
14. **+3V3 output capacitance (BR-01, BR-03, BR-06, BR-08, BR-09, BR-04, BR-13).**
    - The set removes C93 (10 µF), moves C122 (1 µF) to +3V3_VTX and removes about nine 100 nF caps from +3V3.
    - The rail goes from about 31 to about 19 µF nominal, about 9-10 µF effective (I). That is still at the LP5912
      10 µF limit.
    - P4 sums it with maker curves. The next levers are PS-O6, or a TLV75533PDRVR in place of U4.
15. **BR-10 x C17 x TPS2116.** C17 stays (PE-2 refuted), re-netted to +5V_BST. If P5 brings U3 VIN2 and U5 VIN within
    about 2 mm, one cap can serve both; TPS2116 VIN2 has no input cap nearby today (power track, incidental).
16. **Superseded and duplicate IDs (counted once).**

    | Kept here | Also covers |
    |---|---|
    | BR-08 (F2) | PS-04 |
    | BR-07 (PS-05) | PE-4 |
    | BR-06 (PS-08) | RV-3 |
    | BR-11 (PS-10) | PE-3 |
    | BR-18 (PS-01) | PE-11 |
    | BR-14 (PS-18) | PE-5, with the X6S MPN |
    | BR-23 (PS-13) | the PE-12 feedback half |
    | OC-3 (V6) | PS-O3 |
    | BR-02 (V2) | PS-12 (fallback) |
    | PS-O7 | PE-14 |
    | BR-09 | PS-06 and PE-6 (synthesis of their verified halves) |

    PS-11 (R69) is counted once, in BR-12, not in BR-03.

---

## 7. Open items for P3 / P4 / P5 (not reductions)

1. **+3V3 output capacitance** against the LP5912 maximum of 10 µF: sum it with maker DC-bias curves (§6 item 14).
2. **X5R parts still in the H1/H3 zones after the set:** C5, C14, C68, C56, C57, C105, C87 and C2 (C80 leaves with
   BR-01).
   - P3 gives them X6S/X7R parts, or P5 moves them.
   - A 1 µF X6S 0201 such as GRM033C81A105ME05D (P3 to confirm) replacing the whole 1 µF line keeps the line count.
3. **Orderability.**
   - GRM155C80J106ME11D (LCSC C237279 S, no DigiKey listing) now carries 8 parts.
   - BC857BM,315 and RC0201FR-0733KL stock was not checked.
   - HQ Online lists only the ESP32-PICO-V3-02.
   - TPS61022RWUR shows 0 at LCSC (O17 watch).
4. **D4 XL-1010RGBC-2812B** runs on +3V3, below its 3.5-5.5 V supply (passives F-E, inherited from
   OpenRX-Lite-UFL). Decide in P4.
5. **RTC6705 supply details (vtx track).** Pin 40 LDD2V5 lacks the reference's 51 Ω + 1 µF filter. Point C103's
   100 pF at PAVDD/BUFVDD (31/32), as in the reference.
6. **Decision log.** The apply-now items go in as **D52+**: CONTEXT says D35+, but D35-D51 are taken. They change:
   - the D17 implementation (BR-03);
   - D34 (BR-10, BR-22);
   - spec §4.8 / §16 (BR-02, BR-15, BR-16);
   - PINMAP §6 (BR-01, BR-02), F1 (BR-04) and F18 (eFuse order).
7. **BR-02 model.** Use `bomred/verify_vfm/pnp_fix.py`. The original `pnp.py` has the base-current sign reversed.
8. **Placement conditions collected from the set:**
   - BR-01 P2 trial;
   - BR-05 0603 sites ≤ 3 mm from EFM8 VDD;
   - BR-08 C54 ≤ 1 mm from pin 54, C49 at pin 44;
   - BR-09 U12 orientation;
   - BR-13 shared cap between U14 and U15;
   - BR-14 shared CIN between the U4 and U21 IN pins;
   - BR-03 C108-to-U22 path.

---
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

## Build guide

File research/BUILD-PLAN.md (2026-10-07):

# Build plan

How OpenAIO-Whoop goes from targets to a NextPCB order. Each phase has a
deliverable, pass criteria a script or a reviewer can check, and a gate. A
phase starts when the previous gate passes. Scope and part choices live in
[DESIGN-SPEC.md](DESIGN-SPEC.md); this file is only the path.

Target: match the BetaFPV Matrix 1S 5IN1 II envelope (1S, integrated serial
ELRS, analog VTX + OSD, 4x ESC, ~26.5 mm body, 3-4 ears) and beat it on
measured ratings, blackbox, repairability and open documentation. Fab and
turnkey assembly: NextPCB, staying DFM-compatible with JLCPCB too.

## Ground rules for the build

- The owner has given the build full authority (2026-10-06), including nets,
  placement and routing, which AGENTS.md otherwise reserves for people. Goal: a
  finished, clean, optimized board.
- The owner rules for every OpenDrone board (pcb-agent-commons
  `lessons/owner-rules.md`, 2026-10-06) apply. In short: no component
  silkscreen, every solder pad labelled, no "Drone" on the board, exact MPN on
  every BOM line, 0201 passives by default, minimal justified capacitance,
  through vias only unless the owner approves otherwise, KiCad features used
  properly (net-class directive labels, stackup with impedance, custom rules,
  keepouts, zone priorities, component classes, design blocks, jobsets),
  floorplan before schematic, and critique rounds until none finds a blocker
  or major.
- KiCad files are changed through KiCad, kicad-skip or the pcbnew / IPC API
  wherever one exists. Where none does (`.kicad_dru` custom rules, the
  stackup, generating schematic content), the file is written by a script, then
  loaded and re-saved by KiCad and passes `kicad-cli` ERC/DRC before it is
  committed.
- The board follows the lineup conventions in
  [LINEUP-CONVENTIONS.md](LINEUP-CONVENTIONS.md). `hardware/tools/check_conventions.py`
  with 0 FAIL is part of every gate from P3 on.
- Every number in a pass criterion is checked by a script in `hardware/tools/`
  or by an independent review, not by the author of the change.
- Every gate ends with critique agents from at least two perspectives
  (electrical, manufacturing, firmware, RF, lineup). The gate passes only when a
  round finds no BLOCKER or MAJOR.
- ERC and DRC run before every push. New violation types or counts are listed
  in the PR.
- At each gate: pull pcb-agent-commons, adopt other boards' lessons, append
  ours to `lessons/OpenAIO-Whoop.md`.

## Phases

| | Phase | Deliverable | Pass criteria |
|---|---|---|---|
| P0 | Spec freeze | `research/DESIGN-SPEC.md`, `research/COMPETITION.md` | Every block has a primary part (MPN, package, distributor stock >= 5x the 50-board quantity, checked date) and a fallback. Area budget per side <= 96 % of usable board area at 0.2 mm body spacing (the method scores the shipping Matrix II at about 96 %, D20); the P2 placement is the binding proof. 5 V rail holds all loads at 3.0 V in with >= 20 % margin on datasheet curves. Per-FET loss at the published ESC rating with a thermal estimate. NextPCB/JLCPCB stackup and rule table with cited capability numbers, through vias only. Draft FC pin map with timer/DMA conflicts checked. |
| P1 | Project setup | Project from hardware-template with outline, stackup, rules | `kicad-cli` ERC and DRC 0 errors. Outline, hole pattern and keepouts match the spec (`check_board_setup.py --spec`). Stackup with impedance, constraints, presets, net classes with colours, custom rules parsed (`check_rules.py`). |
| P2 | Floorplan proof | Board with every part placed roughly per block on its side, connectors, pads and labels final | Every block's parts fit their region with the 0.2 mm body rule (script). Every solder pad has its label at the minimum legible size. Connectors and pads match the frame and wiring direction. Renders. |
| P3 | Library | Symbols, footprints, 3D models for every BOM line | MPN, manufacturer, datasheet per part. Footprints checked against the datasheet land pattern within 0.02 mm (script). Courtyards normalised to max(body, land) + 0.10 mm so courtyard DRC enforces spacing. Dense variants list every change and why it is safe. |
| P4 | Schematic | Hierarchical sheets following the floorplan | ERC 0 errors, every warning justified. Netlist script: no single-pin nets, every IC supply pin decoupled, BOM fields complete. FC pin map matches the Betaflight target table (script). Net-class directive labels on power, motor and RF nets. |
| P5 | Placement | Final placement synced from the schematic | Parity 0. Body gap >= 0.20 mm (script). Courtyard DRC clean. RF keepouts, gyro placement and power loops per spec. |
| P6 | Routing | Routed board | DRC 0 errors, 0 unconnected, parity 0. Power path cross-section meets the spec current (script). RF lines at 50 ohm for the stackup. |
| P7 | Fab package | NextPCB Gerbers, drill, BOM, CPL, renders, jobset | Package passes NextPCB DFM. Every BOM line orderable by MPN through NextPCB turnkey (consigned parts listed). Quote attached. Owner places the order. |

## Risks carried through every phase

- RTC6705 is broker-only (no LCSC or HQ Online stock): plan a partial-turnkey
  order with consigned parts, and confirm traceability before P7.
- Routing density with through vias only: P6 is where a whoop AIO is won or
  lost. Filled and capped via-in-pad keeps through vias usable under parts on
  both sides; if the area budget still does not close, HDI is put to the owner
  as a decision, with the numbers.
- Stackup is copied from measurement only once a physical Matrix II board has
  been sectioned; until then it is the spec's estimate.

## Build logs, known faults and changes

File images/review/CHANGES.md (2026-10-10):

# Review pack: routing loop 2, promotion 2 (2026-10-10 08:50)

Compared against `p2v3/route/ckpt/loop2_repo_before_promote2.kicad_pcb` (= loop 2 promotion 1, md5 8e30ed8e). The
promotion 1 pack is archived in `p2v3/route/ckpt/review_loop2_promote1/`. Nothing is committed.

## What changed (copper only; no footprint moved: `diff-top.png` / `diff-bottom.png` show no change)
- **11 GND stitching vias removed** (red dots in `copper-diff-top.png`). These are the GND vias that a soft-obstacle
  router (`p2v3/route/loop2/tools/blame.py`) found on the cheapest path of an unrouted edge. A via was removed only when
  the pcbnew unconnected count did not rise. Vias inside RF rule areas (+1 mm) and within 1.2 mm of FET, boost or
  inductor pads were not touched (D33 hot loops, D72 budgets).
- **The D85 inner-layer rules are in the repo DRU now** (applied at 07:57 outside this loop). The edge router now
  uses In2 for Gate, gyro bus, VTX SPI and digital PA control nets. Analog, RF, SHUNT_SENSE, PA_DET, PA_NTC and the
  crystal nets stay off In2.
- **Edge router passes** (`erouter.py`, exact clearance checker, F/B/In2). Pass windows were widened to 3 mm and up to
  5 vias were allowed. Result: +5 vias, F +8.3 mm, B +2.0 mm, In2 +20.9 mm (`copper-diff-*.png`).
- A router-made 0.12 mm +BATT_IN In2 sliver was deleted again. It counted as a connection, but it is not a real
  battery path. +BATT_IN is now excluded from the edge router.
- 3 router track ends were snapped onto the centres of existing vias.

## Numbers (kicad-cli DRC in the repo dir, refill, schematic parity, repo project rules incl. D85)
| | loop 2 promotion 1 | **loop 2 promotion 2** |
|---|---|---|
| DRC errors | 0 | **0** |
| unconnected | 258 | **251** |
| parity | 0 | **0** |
| vias | 344 | **338** |
| track | 556 mm | **591 mm** (F 246 / In2 153 / B 193) |
| warnings | 19 | **21** (+1 connection_width: a 0.02 mm +3V3 router stub at U10 pin 45; +1 track_not_centered_on_via) |
check_spacing --d70: 0 pairs below 0.20 mm, 0 parts within 0.20 mm of the edge. The 3 keepout overlaps are AE1 in its
own antenna areas, the same as before. Edge check: 0 new items outside Edge.Cuts.

## Where the 251 are (`unrouted-map.png`, F + In2 + B)
Unconnected pad ends per sheet: VTX 84, RP2350A 73, RX 38, ESC3 35, POWER 31, ESC4 27, ESC2 26, ESC1 25, OSD 24,
PADS 15, IMU 9, LED 6, BLACKBOX 3.

## Why most of the rest needs placement work (loop 2 analysis, tools in `p2v3/route/loop2/tools`)
- **Via sites are the scarce resource.** `viamap.py` / `viawhy2.py` find only about 9 mm2 of legal through-via sites
  for a generic signal net on the whole board. Stripping all signal copper only doubles that. The main blockers are
  pads on F (1629 grid points blocked by F pads alone) and B (911), GND vias (605), rule areas (530) and F silk (411).
- **The rest of the routing is blocked by placement.** `blame.py` routes each failing edge with movable items made
  passable at a penalty. Movable items are 2-pad passives, test vias, and other nets' tracks and vias.
  - 168 of 241 edges have a path through movable items only.
  - 54 edges are blocked by fixed items (IC, FET and connector pads, rule areas).
  - Only 18 edges are blocked by copper alone. Ripping those nets and routing them again gave no gain (258 -> 259).
  - Most paths are blocked by passives (top: L2 14, C52 12, C117/R16/R14/C108/R20/R25 9).
  - `relocate.py` (radius 1.6 mm, 4 rotations) found no legal site for 11 of the 14 passives that carry no copper.
  - The board has no room for local moves. The next step is a re-placement of the U10 ring, the EFM8 sides and the
    VTX R/C network with reserved escape channels and via sites.
- **D71 pin map (proposal, not applied).** U10 pin use is scrambled. The gyro on the right is fed from left and
  bottom pins, the flash on the bottom left from right pins, and M3/M4 on the left from right pins.
  - `pinopt.py` checks firmware-legal sets (PINMAP 4.4), the EXT-USER-PADS / I2C-USER / I2C-HD presets and the OSD
    triple. It cuts escape-aware length from 333 to about 201 (`p2v3/route/loop2/an/pinmap_A.json`).
  - A PCB-only trial routed only +2 to +3 more edges, so the schematic, PINMAP and Betaflight-config swap is deferred.
    Re-plan it together with the U10 re-placement.

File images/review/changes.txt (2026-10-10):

footprints: same 272
counts old {'tracks': 1115, 'vias': 344, 'zones': 72, 'footprints': 272}
counts new {'tracks': 1173, 'vias': 338, 'zones': 72, 'footprints': 272}

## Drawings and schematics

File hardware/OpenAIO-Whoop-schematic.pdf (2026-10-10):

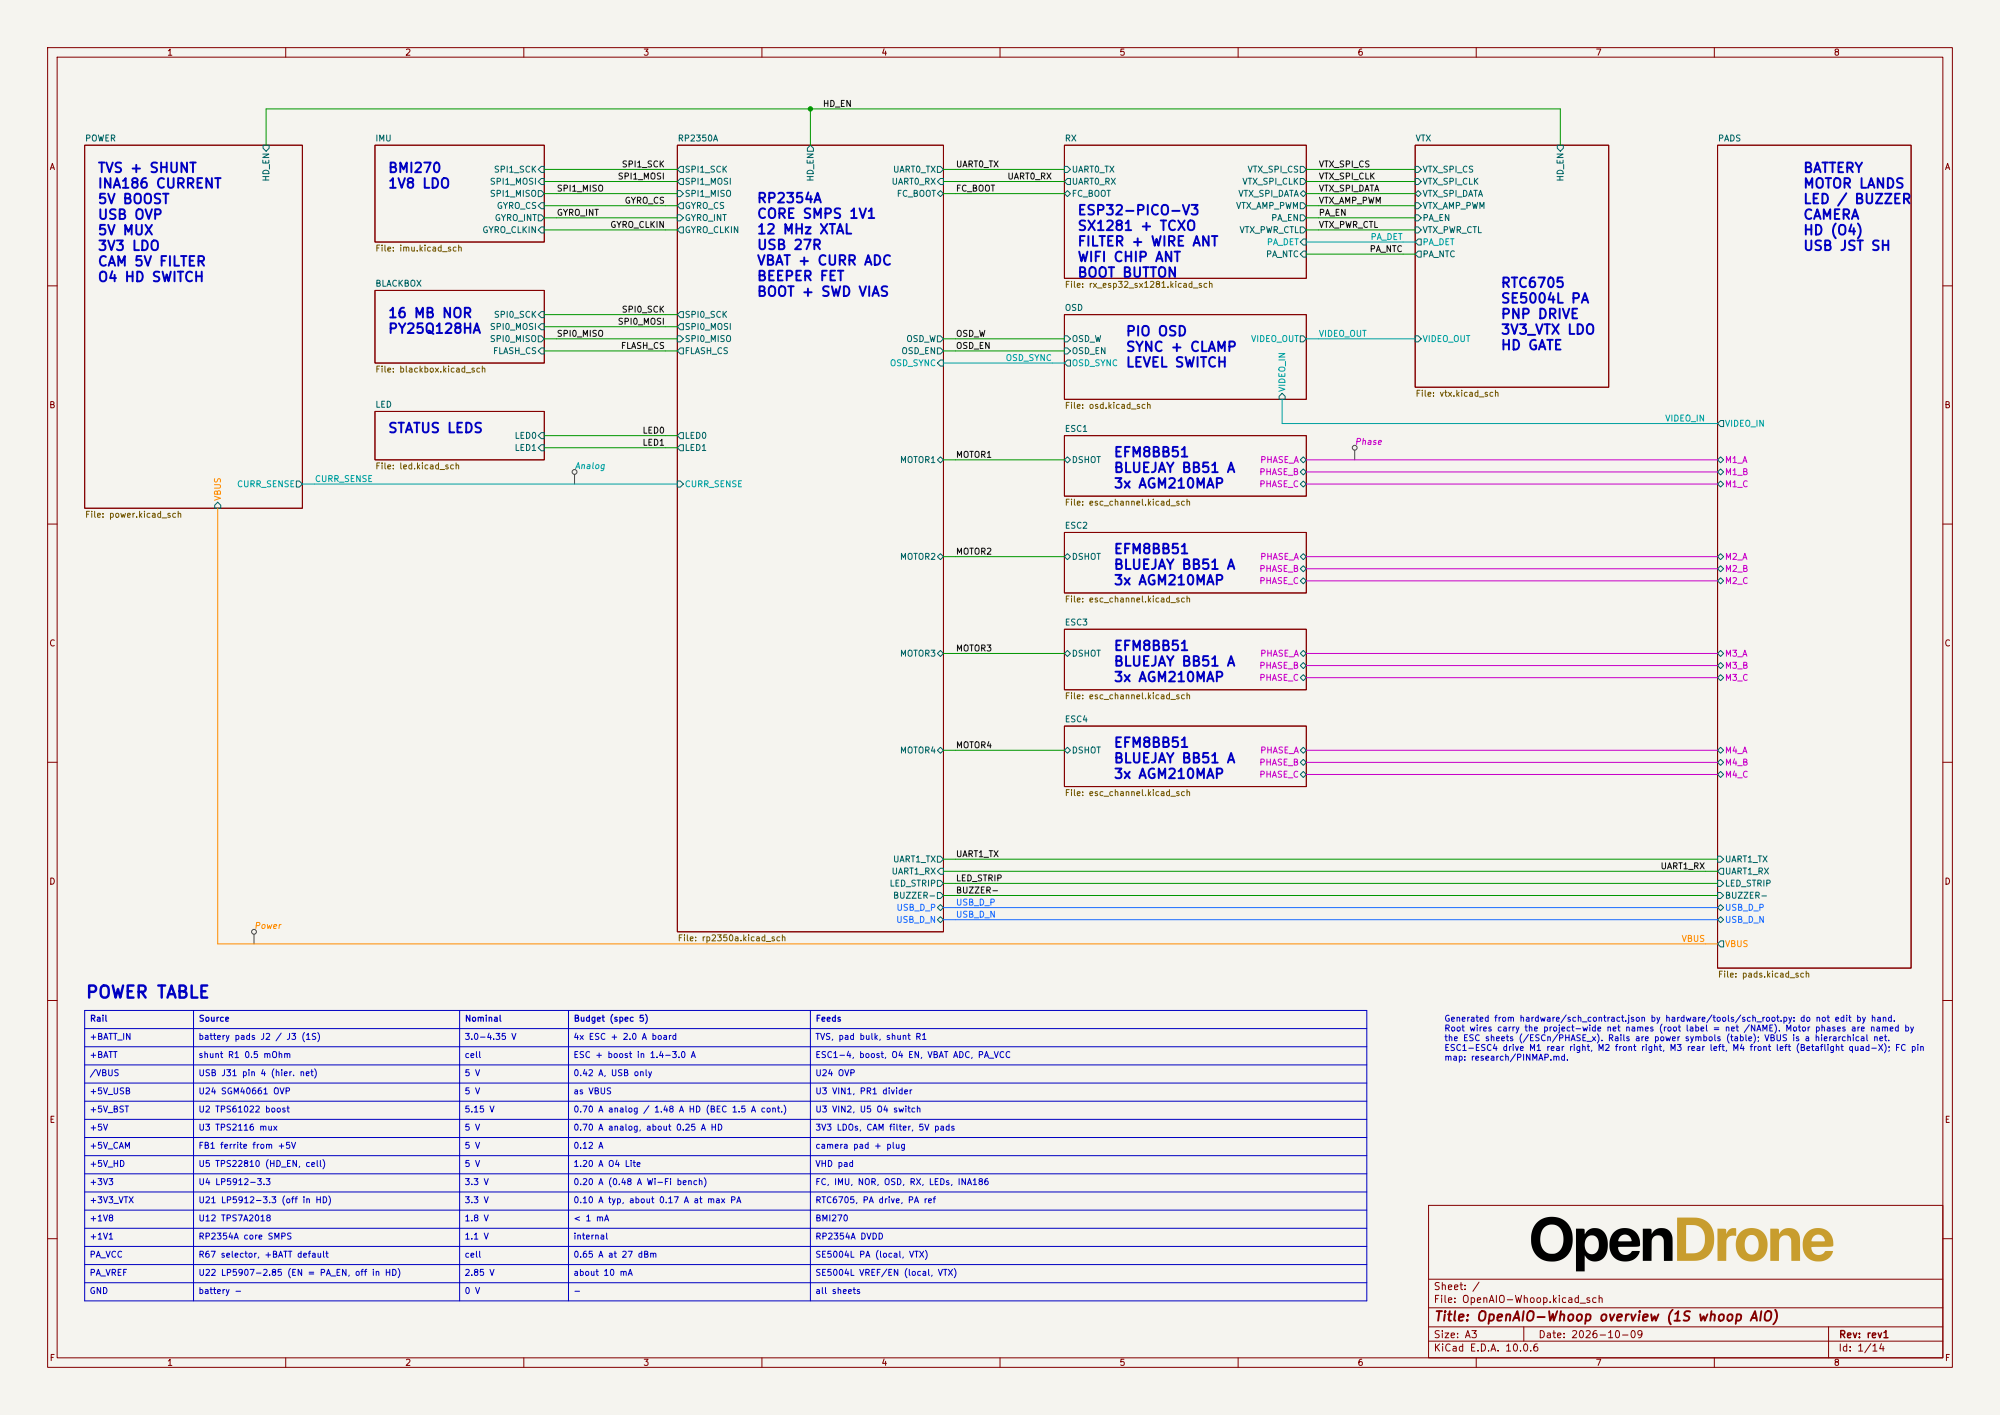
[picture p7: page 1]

the ESC sheets (/ESCn/PHASE_x). Rails are power symbols (table); VBUS is a hierarchical net. ESC1-ESC4 drive M1 rear right, M2 front right, M3 rear left, M4 front left (Betaflight quad-X); FC pin map: research/PINMAP.md.

Sheet: /
File: OpenAIO-Whoop.kicad_sch
Title: OpenAIO-Whoop overview (1S whoop AIO)

Size: A3 | Rev: rev1 | F Date: 2026-10-09
KiCad E.D.A. 10.0.6 | Id: 1/14

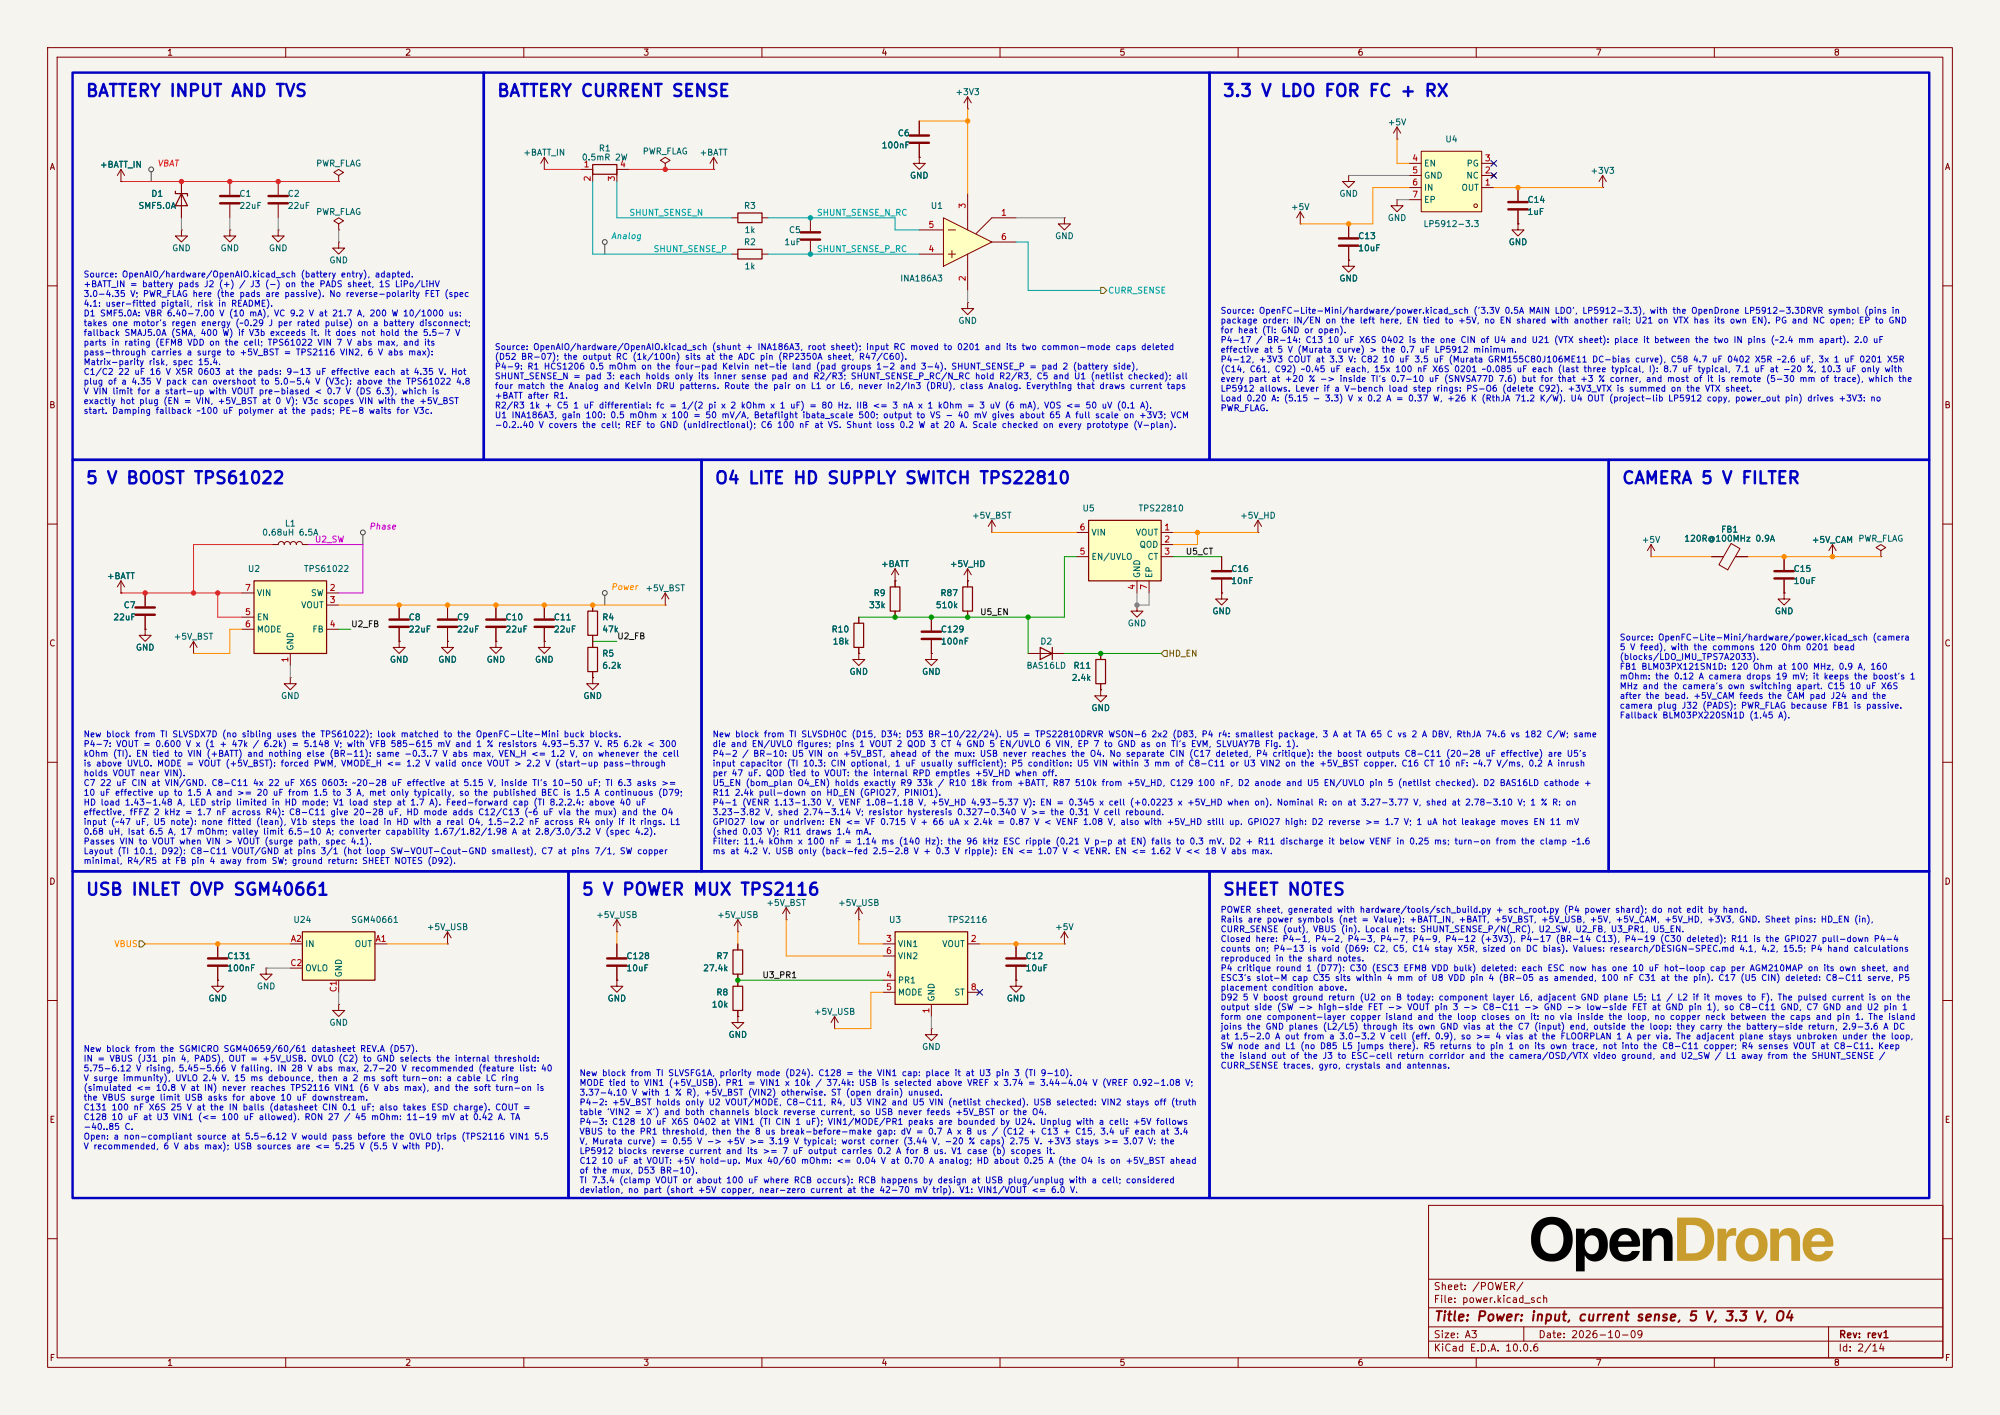
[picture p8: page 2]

LP5912 allows. Lever if a V-bench load step rings: PS-O6 (delete C92). +3V3_VTX is summed on the VTX sheet. Load 0.20 A: (5.15 - 3.3) V x 0.2 A = 0.37 W, +26 K (RthJA 71.2 K/W). U4 OUT (project-lib LP5912 copy, power_out pin) drives +3V3: no PWR_FLAG. Source: OpenAIO/hardware/OpenAIO.kicad_sch (battery entry), adapted. +BATT_IN = battery pads J2 (+) / J3 (-) on the PADS sheet, 1S LiPo/LiHV 3.0-4.35 V; PWR_FLAG here (the pads are passive). No reverse-polarity FET (spec 4.1: user-fitted pigtail, risk in README). D1 SMF5.0A: VBR 6.40-7.00 V (10 mA), VC 9.2 V at 21.7 A, 200 W 10/1000 us: takes one motor's regen energy (~0.29 J per rated pulse) on a battery disconnect; fallback SMAJ5.0A (SMA, 400 W) if V3b exceeds it. It does not hold the 5.5-7 V parts in rating (EFM8 VDD on the cell; TPS61022 VIN 7 V abs max, and its pass-through carries a surge to +5V_BST = TPS2116 VIN2, 6 V abs max):

Source: OpenFC-Lite-Mini/hardware/power.kicad_sch ('3.3V 0.5A MAIN LDO', LP5912-3.3), with the OpenDrone LP5912-3.3DRVR symbol (pins in
package order: IN/EN on the left here, EN tied to +5V, no EN shared with another rail; U21 on VTX has its own EN). PG and NC open; EP to GND
for heat (TI: GND or open). P4-17 / BR-14: C13 10 uF X6S 0402 is the one CIN of U4 and U21 (VTX sheet): place it between the two IN pins (~2.4 mm apart). 2.0 uF

camera plug J32 (PADS); PWR_FLAG because FB1 is passive. Fallback BLM03PX220SN1D (1.45 A). Source: OpenAIO/hardware/OpenAIO.kicad_sch (shunt + INA186A3, root sheet); input RC moved to 0201 and its two common-mode caps deleted
(D52 BR-07); the output RC (1k/100n) sits at the ADC pin (RP2350A sheet, R47/C60). P4-9: R1 HCS1206 0.5 mOhm on the four-pad Kelvin net-tie land (pad groups 1-2 and 3-4). SHUNT_SENSE_P = pad 2 (battery side), SHUNT_SENSE_N = pad 3: each holds only its inner sense pad and R2/R3; SHUNT_SENSE_P_RC/N_RC hold R2/R3, C5 and U1 (netlist checked); all four match the Analog and Kelvin DRU patterns. Route the pair on L1 or L6, never In2/In3 (DRU), class Analog. Everything that draws current taps +BATT after R1. R2/R3 1k + C5 1 uF differential: fc = 1/(2 pi x 2 kOhm x 1 uF) = 80 Hz. IIB <= 3 nA x 1 kOhm = 3 uV (6 mA), VOS <= 50 uV (0.1 A). U1 INA186A3, gain 100: 0.5 mOhm x 100 = 50 mV/A, Betaflight ibata_scale 500; output to VS - 40 mV gives about 65 A full scale on +3V3; VCM -0.2..40 V covers the cell; REF to GND (unidirectional); C6 100 nF at VS. Shunt loss 0.2 W at 20 A. Scale checked on every prototype (V-plan). New block from TI SLVSDH0C (D15, D34; D53 BR-10/22/24). U5 = TPS22810DRVR WSON-6 2x2 (D83, P4 r4: smallest package, 3 A at TA 65 C vs 2 A DBV, RthJA 74.6 vs 182 C/W; same die and EN/UVLO figures; pins 1 VOUT 2 QOD 3 CT 4 GND 5 EN/UVLO 6 VIN, EP 7 to GND as on TI's EVM, SLVUAY7B Fig. 1). P4-2 / BR-10: U5 VIN on +5V_BST, ahead of the mux: USB never reaches the O4. No separate CIN (C17 deleted, P4 critique): the boost outputs C8-C11 (20-28 uF effective) are U5's

effective at 5 V (Murata curve) > the 0.7 uF LP5912 minimum. P4-12, +3V3 COUT at 3.3 V: C82 10 uF 3.5 uF (Murata GRM155C80J106ME11 DC-bias curve), C58 4.7 uF 0402 X5R ~2.6 uF, 3x 1 uF 0201 X5R

Matrix-parity risk, spec 15.4. C1/C2 22 uF 16 V X5R 0603 at the pads: 9-13 uF effective each at 4.35 V. Hot plug of a 4.35 V pack can overshoot to 5.0-5.4 V (V3c): above the TPS61022 4.8

(C14, C61, C92) ~0.45 uF each, 15x 100 nF X6S 0201 ~0.085 uF each (last three typical, I): 8.7 uF typical, 7.1 uF at -20 %, 10.3 uF only with
every part at +20 % -> inside TI's 0.7-10 uF (SNVSA77D 7.6) but for that +3 % corner, and most of it is remote (5-30 mm of trace), which the

V VIN limit for a start-up with VOUT pre-biased < 0.7 V (DS 6.3), which is exactly hot plug (EN = VIN, +5V_BST at 0 V); V3c scopes VIN with the +5V_BST start. Damping fallback ~100 uF polymer at the pads; PE-8 waits for V3c.

O4 LITE HD SUPPLY SWITCH TPS22810

Source: OpenFC-Lite-Mini/hardware/power.kicad_sch (camera 5 V feed), with the commons 120 Ohm 0201 bead

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

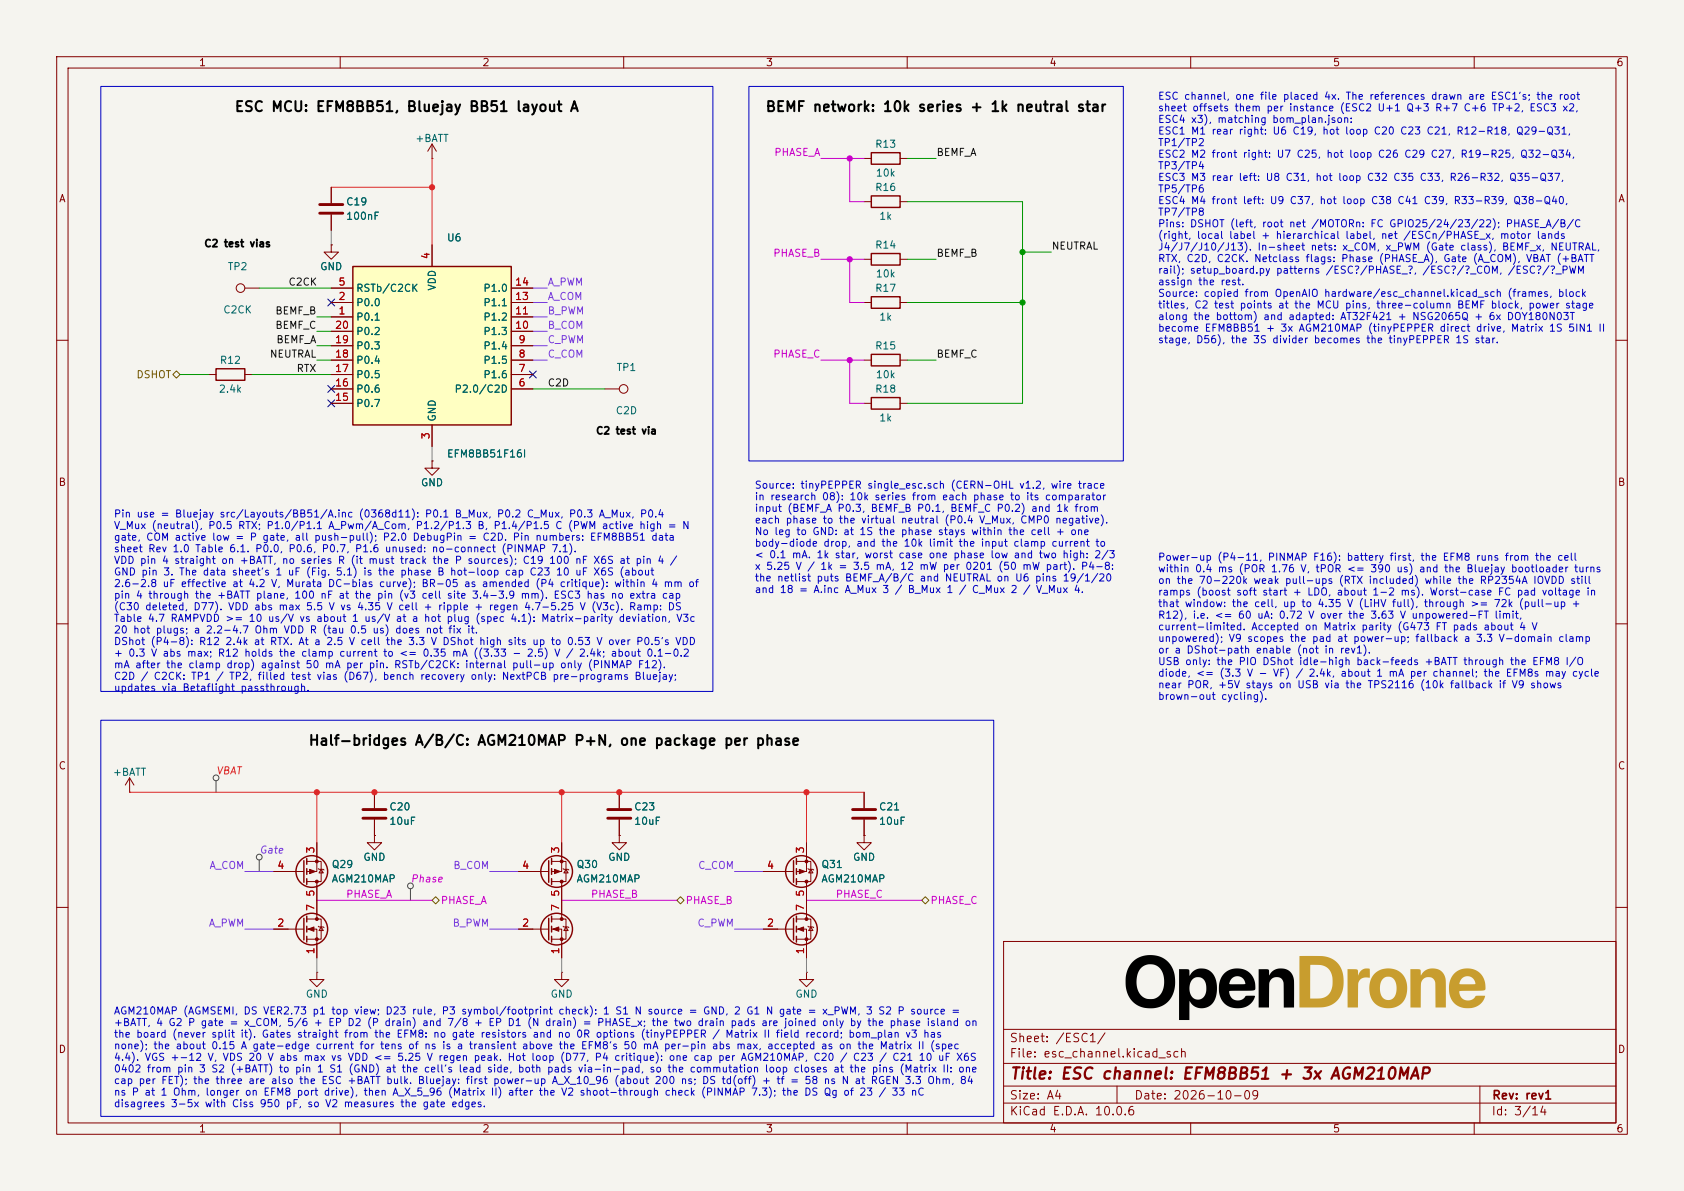
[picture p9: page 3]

ESC MCU: EFM8BB51, Bluejay BB51 layout A
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

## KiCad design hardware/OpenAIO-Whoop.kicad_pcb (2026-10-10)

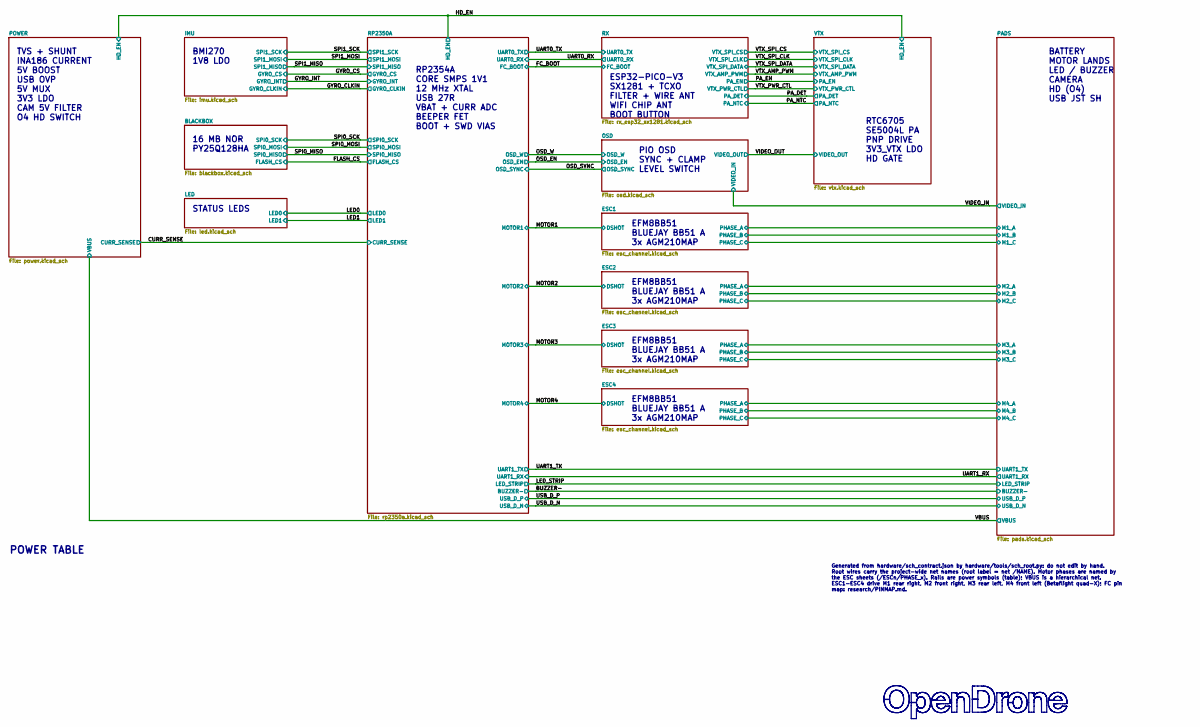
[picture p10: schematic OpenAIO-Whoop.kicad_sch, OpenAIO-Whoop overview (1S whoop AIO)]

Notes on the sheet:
PIO OSD SYNC + CLAMP LEVEL SWITCH
EFM8BB51 BLUEJAY BB51 A 3x AGM210MAP
16 MB NOR PY25Q128HA
POWER TABLE
STATUS LEDS
ESP32-PICO-V3 SX1281 + TCXO FILTER + WIRE ANT WIFI CHIP ANT BOOT BUTTON
TVS + SHUNT INA186 CURRENT 5V BOOST USB OVP 5V MUX 3V3 LDO CAM 5V FILTER O4 HD SWITCH
BATTERY MOTOR LANDS LED / BUZZER CAMERA HD (O4) USB JST SH
RTC6705 SE5004L PA PNP DRIVE 3V3_VTX LDO HD GATE
RP2354A CORE SMPS 1V1 12 MHz XTAL USB 27R VBAT + CURR ADC BEEPER FET BOOT + SWD VIAS
BMI270 1V8 LDO
Generated from hardware/sch_contract.json by hardware/tools/sch_root.py: do not edit by hand. Root wires carry the project-wide net names (root label = net /NAME). Motor phases are named by the ESC sheets (/ESCn/PHASE_x). Rails are power symbols (table); VBUS is a hierarchical net. ESC1-ESC4 drive 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

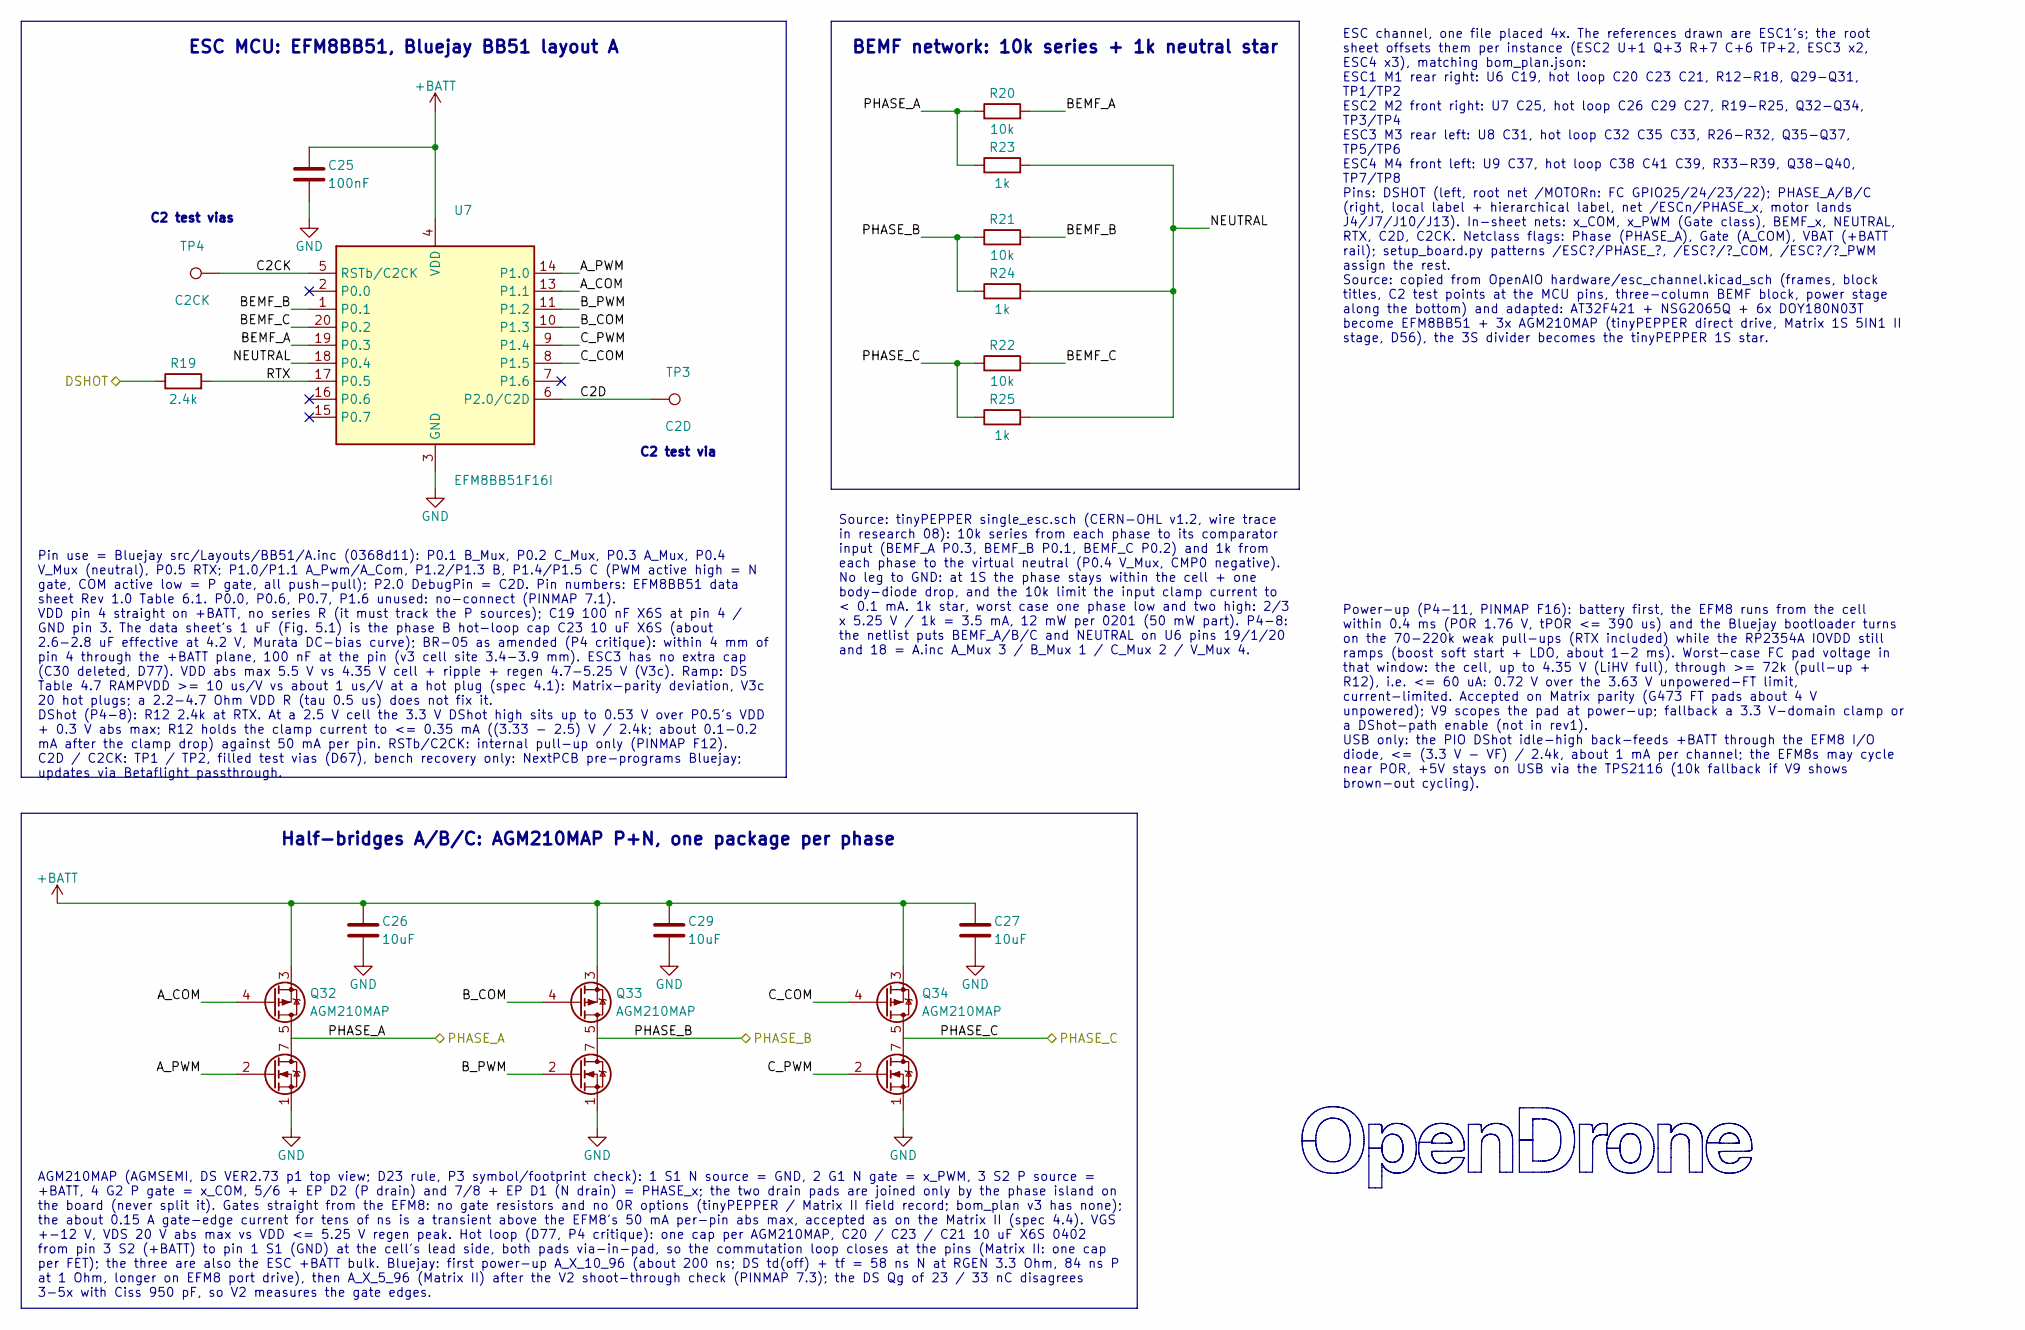
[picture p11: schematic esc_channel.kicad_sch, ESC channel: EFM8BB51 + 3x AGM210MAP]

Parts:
C25: 100nF; C_0201_0603Metric_W; MPN GRM033C81E104KE14D; LCSC C181047
C26, C27, C29: 10uF; C_0402_1005Metric_W; MPN GRM155C80J106ME11D; LCSC C237279
Q32, Q33, Q34: AGM210MAP; AGM_PDFN-8-2EP_3.3x3.3mm_AGM210MAP; MPN AGM210MAP; LCSC C7431169
R19: 2.4k; R_0201_0603Metric_W; MPN RTT012401FTH; LCSC C166281
R20, R21, R22: 10k; R_0201_0603Metric_W; MPN RC0201FR-0710KL; LCSC C106225
R23, R24, R25: 1k; R_0201_0603Metric_W; MPN RC0201FR-071KL
TP3: C2D; TestPoint_Via_D0.35mm_Drill0.2mm
TP4: C2CK; TestPoint_Via_D0.35mm_Drill0.2mm
U7: EFM8BB51F16I; QFN-20_3x3mm_P0.5mm_EFM8BB51; MPN EFM8BB51F16I-C-QFN20R

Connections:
+BATT: C25.1, C26.1, C27.1, C29.1, Q32.3 (S2), Q33.3 (S2), Q34.3 (S2), U7.4 (VDD); also elsewhere on the board
/ESC2/A_COM: Q32.4 (G2), U7.13 (P1.1)
/ESC2/A_PWM: Q32.2 (G1), U7.14 (P1.0)
/ESC2/BEMF_A: R20.2, U7.19 (P0.3)
/ESC2/BEMF_B: R21.2, U7.1 (P0.1)
/ESC2/BEMF_C: R22.2, U7.20 (P0.2)
/ESC2/B_COM: Q33.4 (G2), U7.10 (P1.3)
/ESC2/B_PWM: Q33.2 (G1), U7.11 (P1.2)
/ESC2/C2CK: TP4.1 (1_1), U7.5 (RSTb/C2CK)
/ESC2/C2D: TP3.1 (1_1), U7.6 (P2.0/C2D)
/ESC2/C_COM: Q34.4 (G2), U7.8 (P1.5)
/ESC2/C_PWM: Q34.2 (G1), U7.9 (P1.4)
/ESC2/NEUTRAL: R23.2, R24.2, R25.2, U7.18 (P0.4)
/ESC2/PHASE_A: Q32.5 (D2), Q32.6 (D2), Q32.7 (D1), Q32.8 (D1), R20.1, R23.1; also elsewhere on the board
/ESC2/PHASE_B: Q33.5 (D2), Q33.6 (D2), Q33.7 (D1), Q33.8 (D1), R21.1, R24.1; also elsewhere on the board
/ESC2/PHASE_C: Q34.5 (D2), Q34.6 (D2), Q34.7 (D1), Q34.8 (D1), R22.1, R25.1; also elsewhere on the board
/ESC2/RTX: R19.2, U7.17 (P0.5)
/MOTOR2: R19.1; also elsewhere on the board
GND: C25.2, C26.2, C27.2, C29.2, Q32.1 (S1), Q33.1 (S1), Q34.1 (S1), U7.3 (GND), U7.12 (GND), U7.21 (GND); also elsewhere on the board

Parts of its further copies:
C19, C31, C37: 100nF; C_0201_0603Metric_W; MPN GRM033C81E104KE14D; LCSC C181047
C20, C21, C23, C32, C33, C35, C38, C39, C41: 10uF; C_0402_1005Metric_W; MPN GRM155C80J106ME11D; LCSC C237279
Q29, Q30, Q31, Q35, Q36, Q37, Q38, Q39, Q40: AGM210MAP; AGM_PDFN-8-2EP_3.3x3.3mm_AGM210MAP; MPN AGM210MAP; LCSC C7431169
R12, R26, R33: 2.4k; R_0201_0603Metric_W; MPN RTT012401FTH; LCSC C166281
R13, R14, R15, R27, R28, R29, R34, R35, R36: 10k; R_0201_0603Metric_W; MPN RC0201FR-0710KL; LCSC C106225
R16, R17, R18, R30, R31, R32, R37, R38, R39: 1k; R_0201_0603Metric_W; MPN RC0201FR-071KL
TP1, TP5, TP7: C2D; TestPoint_Via_D0.35mm_Drill0.2mm
TP2, TP6, TP8: C2CK; TestPoint_Via_D0.35mm_Drill0.2mm
U6, U8, U9: EFM8BB51F16I; QFN-20_3x3mm_P0.5mm_EFM8BB51; MPN EFM8BB51F16I-C-QFN20R

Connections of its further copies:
+BATT: C19.1, C20.1, C21.1, C23.1, C31.1, C32.1, C33.1, C35.1, C37.1, C38.1, C39.1, C41.1, Q29.3 (S2), Q30.3 (S2), Q31.3 (S2), Q35.3 (S2), Q36.3 (S2), Q37.3 (S2), Q38.3 (S2), Q39.3 (S2), Q40.3 (S2), U6.4 (VDD), U8.4 (VDD), U9.4 (VDD); also elsewhere on the board
/ESC1/A_COM: Q29.4 (G2), U6.13 (P1.1)
/ESC1/A_PWM: Q29.2 (G1), U6.14 (P1.0)
/ESC1/BEMF_A: R13.2, U6.19 (P0.3)
/ESC1/BEMF_B: R14.2, U6.1 (P0.1)
/ESC1/BEMF_C: R15.2, U6.20 (P0.2)
/ESC1/B_COM: Q30.4 (G2), U6.10 (P1.3)
/ESC1/B_PWM: Q30.2 (G1), U6.11 (P1.2)
/ESC1/C2CK: TP2.1 (1_1), U6.5 (RSTb/C2CK)
/ESC1/C2D: TP1.1 (1_1), U6.6 (P2.0/C2D)
/ESC1/C_COM: Q31.4 (G2), U6.8 (P1.5)
/ESC1/C_PWM: Q31.2 (G1), U6.9 (P1.4)
/ESC1/NEUTRAL: R16.2, R17.2, R18.2, U6.18 (P0.4)
/ESC1/PHASE_A: Q29.5 (D2), Q29.6 (D2), Q29.7 (D1), Q29.8 (D1), R13.1, R16.1; also elsewhere on the board
/ESC1/PHASE_B: Q30.5 (D2), Q30.6 (D2), Q30.7 (D1), Q30.8 (D1), R14.1, R17.1; also elsewhere on the board
/ESC1/PHASE_C: Q31.5 (D2), Q31.6 (D2), Q31.7 (D1), Q31.8 (D1), R15.1, R18.1; also elsewhere on the board
/ESC1/RTX: R12.2, U6.17 (P0.5)
/ESC3/A_COM: Q35.4 (G2), U8.13 (P1.1)
/ESC3/A_PWM: Q35.2 (G1), U8.14 (P1.0)
/ESC3/BEMF_A: R27.2, U8.19 (P0.3)
/ESC3/BEMF_B: R28.2, U8.1 (P0.1)
/ESC3/BEMF_C: R29.2, U8.20 (P0.2)
/ESC3/B_COM: Q36.4 (G2), U8.10 (P1.3)
/ESC3/B_PWM: Q36.2 (G1), U8.11 (P1.2)
/ESC3/C2CK: TP6.1 (1_1), U8.5 (RSTb/C2CK)
/ESC3/C2D: TP5.1 (1_1), U8.6 (P2.0/C2D)
/ESC3/C_COM: Q37.4 (G2), U8.8 (P1.5)
/ESC3/C_PWM: Q37.2 (G1), U8.9 (P1.4)
/ESC3/NEUTRAL: R30.2, R31.2, R32.2, U8.18 (P0.4)
/ESC3/PHASE_A: Q35.5 (D2), Q35.6 (D2), Q35.7 (D1), Q35.8 (D1), R27.1, R30.1; also elsewhere on the board
/ESC3/PHASE_B: Q36.5 (D2), Q36.6 (D2), Q36.7 (D1), Q36.8 (D1), R28.1, R31.1; also elsewhere on the board
/ESC3/PHASE_C: Q37.5 (D2), Q37.6 (D2), Q37.7 (D1), Q37.8 (D1), R29.1, R32.1; also elsewhere on the board
/ESC3/RTX: R26.2, U8.17 (P0.5)
/ESC4/A_COM: Q38.4 (G2), U9.13 (P1.1)
/ESC4/A_PWM: Q38.2 (G1), U9.14 (P1.0)
/ESC4/BEMF_A: R34.2, U9.19 (P0.3)
/ESC4/BEMF_B: R35.2, U9.1 (P0.1)
/ESC4/BEMF_C: R36.2, U9.20 (P0.2)
/ESC4/B_COM: Q39.4 (G2), U9.10 (P1.3)
/ESC4/B_PWM: Q39.2 (G1), U9.11 (P1.2)
/ESC4/C2CK: TP8.1 (1_1), U9.5 (RSTb/C2CK)
/ESC4/C2D: TP7.1 (1_1), U9.6 (P2.0/C2D)
/ESC4/C_COM: Q40.4 (G2), U9.8 (P1.5)
/ESC4/C_PWM: Q40.2 (G1), U9.9 (P1.4)
/ESC4/NEUTRAL: R37.2, R38.2, R39.2, U9.18 (P0.4)
/ESC4/PHASE_A: Q38.5 (D2), Q38.6 (D2), Q38.7 (D1), Q38.8 (D1), R34.1, R37.1; also elsewhere on the board
/ESC4/PHASE_B: Q39.5 (D2), Q39.6 (D2), Q39.7 (D1), Q39.8 (D1), R35.1, R38.1; also elsewhere on the board
/ESC4/PHASE_C: Q40.5 (D2), Q40.6 (D2), Q40.7 (D1), Q40.8 (D1), R36.1, R39.1; also elsewhere on the board
/ESC4/RTX: R33.2, U9.17 (P0.5)
/MOTOR1: R12.1; also elsewhere on the board
/MOTOR3: R26.1; also elsewhere on the board
/MOTOR4: R33.1; also elsewhere on the board
GND: C19.2, C20.2, C21.2, C23.2, C31.2, C32.2, C33.2, C35.2, C37.2, C38.2, C39.2, C41.2, Q29.1 (S1), Q30.1 (S1), Q31.1 (S1), Q35.1 (S1), Q36.1 (S1), Q37.1 (S1), Q38.1 (S1), Q39.1 (S1), Q40.1 (S1), U6.3 (GND), U6.12 (GND), U6.21 (GND), U8.3 (GND), U8.12 (GND), U8.21 (GND), U9.3 (GND), U9.12 (GND), U9.21 (GND); also elsewhere on the board

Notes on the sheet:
C2 test vias
Half-bridges A/B/C: AGM210MAP P+N, one package per phase
ESC MCU: EFM8BB51, Bluejay BB51 layout A
BEMF network: 10k series + 1k neutral star
C2 test via
AGM210MAP (AGMSEMI, DS VER2.73 p1 top view; D23 rule, P3 symbol/footprint check): 1 S1 N source = GND, 2 G1 N gate = x_PWM, 3 S2 P source = +BATT, 4 G2 P gate = x_COM, 5/6 + EP D2 (P drain) and 7/8 + EP D1 (N drain) = PHASE_x; the two drain pads are joined only by the phase island on the board (nev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
ESC channel, one file placed 4x. The references drawn are ESC1's; the root sheet offsets them per instance (ESC2 U+1 Q+3 R+7 C+6 TP+2, ESC3 x2, ESC4 x3), matching bom_plan.json: ESC1 M1 rear right: U6 C19, hot loop C20 C23 C21, R12-R18, Q29-Q31, TP1/TP2 ESC2 M2 front right: U7 C25, hot loop C26 C29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
Power-up (P4-11, PINMAP F16): battery first, the EFM8 runs from the cell within 0.4 ms (POR 1.76 V, tPOR <= 390 us) and the Bluejay bootloader turns on the 70-220k weak pull-ups (RTX included) while the RP2354A IOVDD still ramps (boost soft start + LDO, about 1-2 ms). Worst-case FC pad voltage in t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
Pin use = Bluejay src/Layouts/BB51/A.inc (0368d11): P0.1 B_Mux, P0.2 C_Mux, P0.3 A_Mux, P0.4 V_Mux (neutral), P0.5 RTX; P1.0/P1.1 A_Pwm/A_Com, P1.2/P1.3 B, P1.4/P1.5 C (PWM active high = N gate, COM active low = P gate, all push-pull); P2.0 DebugPin = C2D. Pin numbers: EFM8BB51 data sheet Rev 1.0 T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
Source: tinyPEPPER single_esc.sch (CERN-OHL v1.2, wire trace in research 08): 10k series from each phase to its comparator input (BEMF_A P0.3, BEMF_B P0.1, BEMF_C P0.2) and 1k from each phase to the virtual neutral (P0.4 V_Mux, CMP0 negative). No leg to GND: at 1S the phase stays within the cell + 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

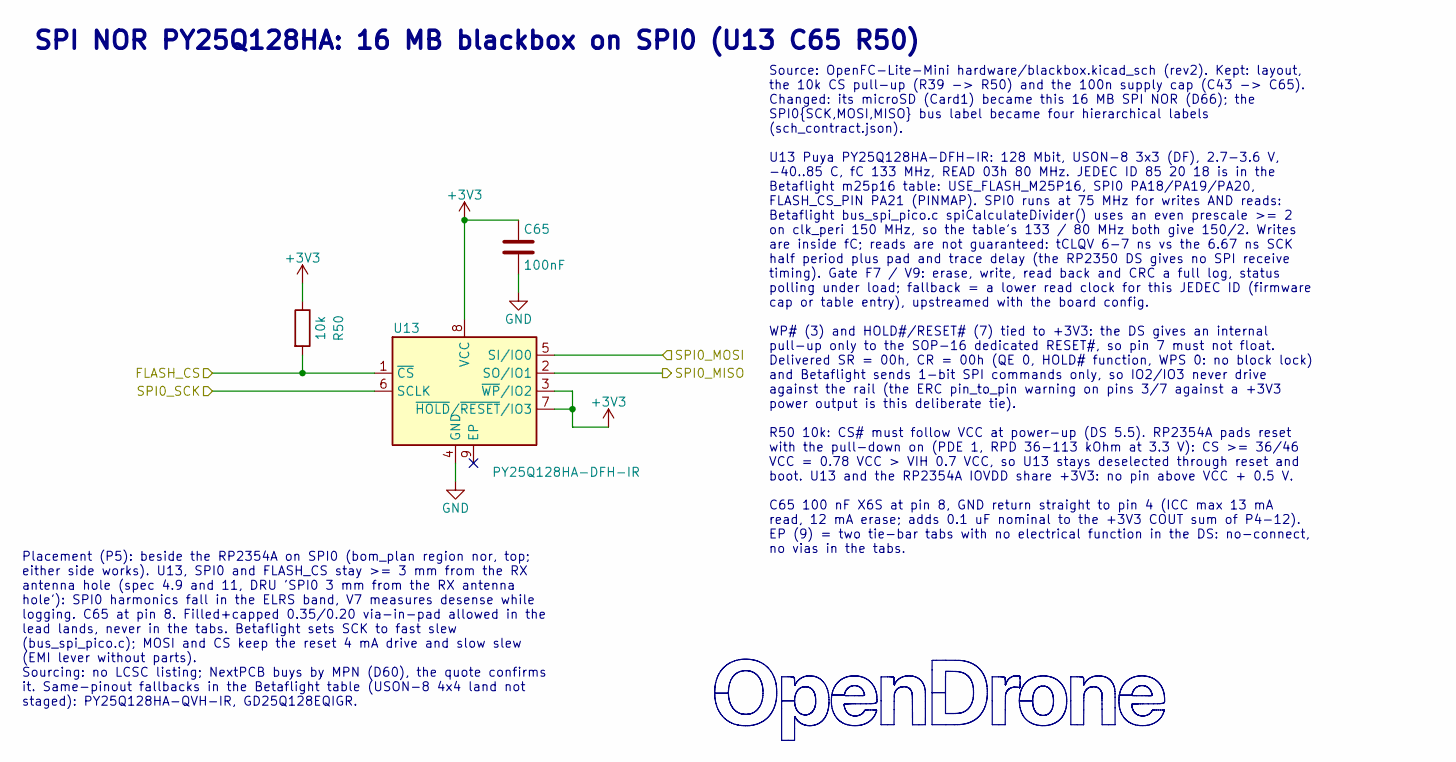
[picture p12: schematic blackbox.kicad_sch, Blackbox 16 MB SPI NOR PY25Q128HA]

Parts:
C65: 100nF; C_0201_0603Metric_W; MPN GRM033C81E104KE14D; LCSC C181047
R50: 10k; R_0201_0603Metric_W; MPN RC0201FR-0710KL; LCSC C106225
U13: PY25Q128HA-DFH-IR; USON-8_3x3mm_P0.8mm_EP_PY25Q128HA; MPN PY25Q128HA-DFH-IR

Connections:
+3V3: C65.1, R50.1, U13.3 (~WP/IO2), U13.7 (~HOLD/~RESET/IO3), U13.8 (VCC); also elsewhere on the board
/FLASH_CS: R50.2, U13.1 (~CS); also elsewhere on the board
/SPI0_MISO: U13.2 (SO/IO1); also elsewhere on the board
/SPI0_MOSI: U13.5 (SI/IO0); also elsewhere on the board
/SPI0_SCK: U13.6 (SCLK); also elsewhere on the board
GND: C65.2, U13.4 (GND); also elsewhere on the board

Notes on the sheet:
SPI NOR PY25Q128HA: 16 MB blackbox on SPI0 (U13 C65 R50)
Placement (P5): beside the RP2354A on SPI0 (bom_plan region nor, top; either side works). U13, SPI0 and FLASH_CS stay >= 3 mm from the RX antenna hole (spec 4.9 and 11, DRU 'SPI0 3 mm from the RX antenna hole'): SPI0 harmonics fall in the ELRS band, V7 measures desense while logging. C65 at pin 8. 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
Source: OpenFC-Lite-Mini hardware/blackbox.kicad_sch (rev2). Kept: layout, the 10k CS pull-up (R39 -> R50) and the 100n supply cap (C43 -> C65). Changed: its microSD (Card1) became this 16 MB SPI NOR (D66); the SPI0{SCK,MOSI,MISO} bus label became four hierarchical labels (sch_contract.json). U13 P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

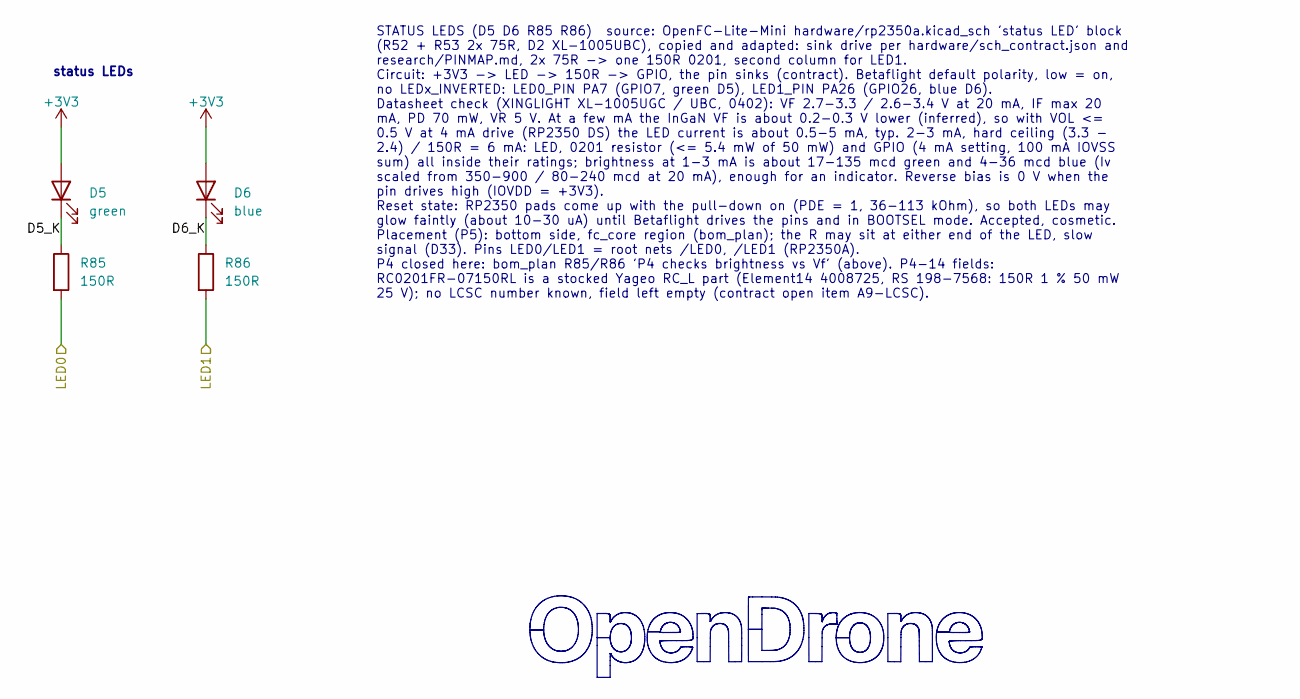
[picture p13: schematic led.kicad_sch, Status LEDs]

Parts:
D5: green; LED_0402_1005Metric; MPN XL-1005UGC; LCSC C965793
D6: blue; LED_0402_1005Metric; MPN XL-1005UBC; LCSC C22355736
R85, R86: 150R; R_0201_0603Metric_W; MPN RC0201FR-07150RL

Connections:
+3V3: D5.2 (A), D6.2 (A); also elsewhere on the board
/LED0: R85.2; also elsewhere on the board
/LED1: R86.2; also elsewhere on the board
/LED/D5_K: D5.1 (K), R85.1
/LED/D6_K: D6.1 (K), R86.1

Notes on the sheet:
status LEDs
STATUS LEDS (D5 D6 R85 R86) source: OpenFC-Lite-Mini hardware/rp2350a.kicad_sch 'status LED' block (R52 + R53 2x 75R, D2 XL-1005UBC), copied and adapted: sink drive per hardware/sch_contract.json and research/PINMAP.md, 2x 75R -> one 150R 0201, second column for LED1. Circuit: +3V3 -> LED -> 150R -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

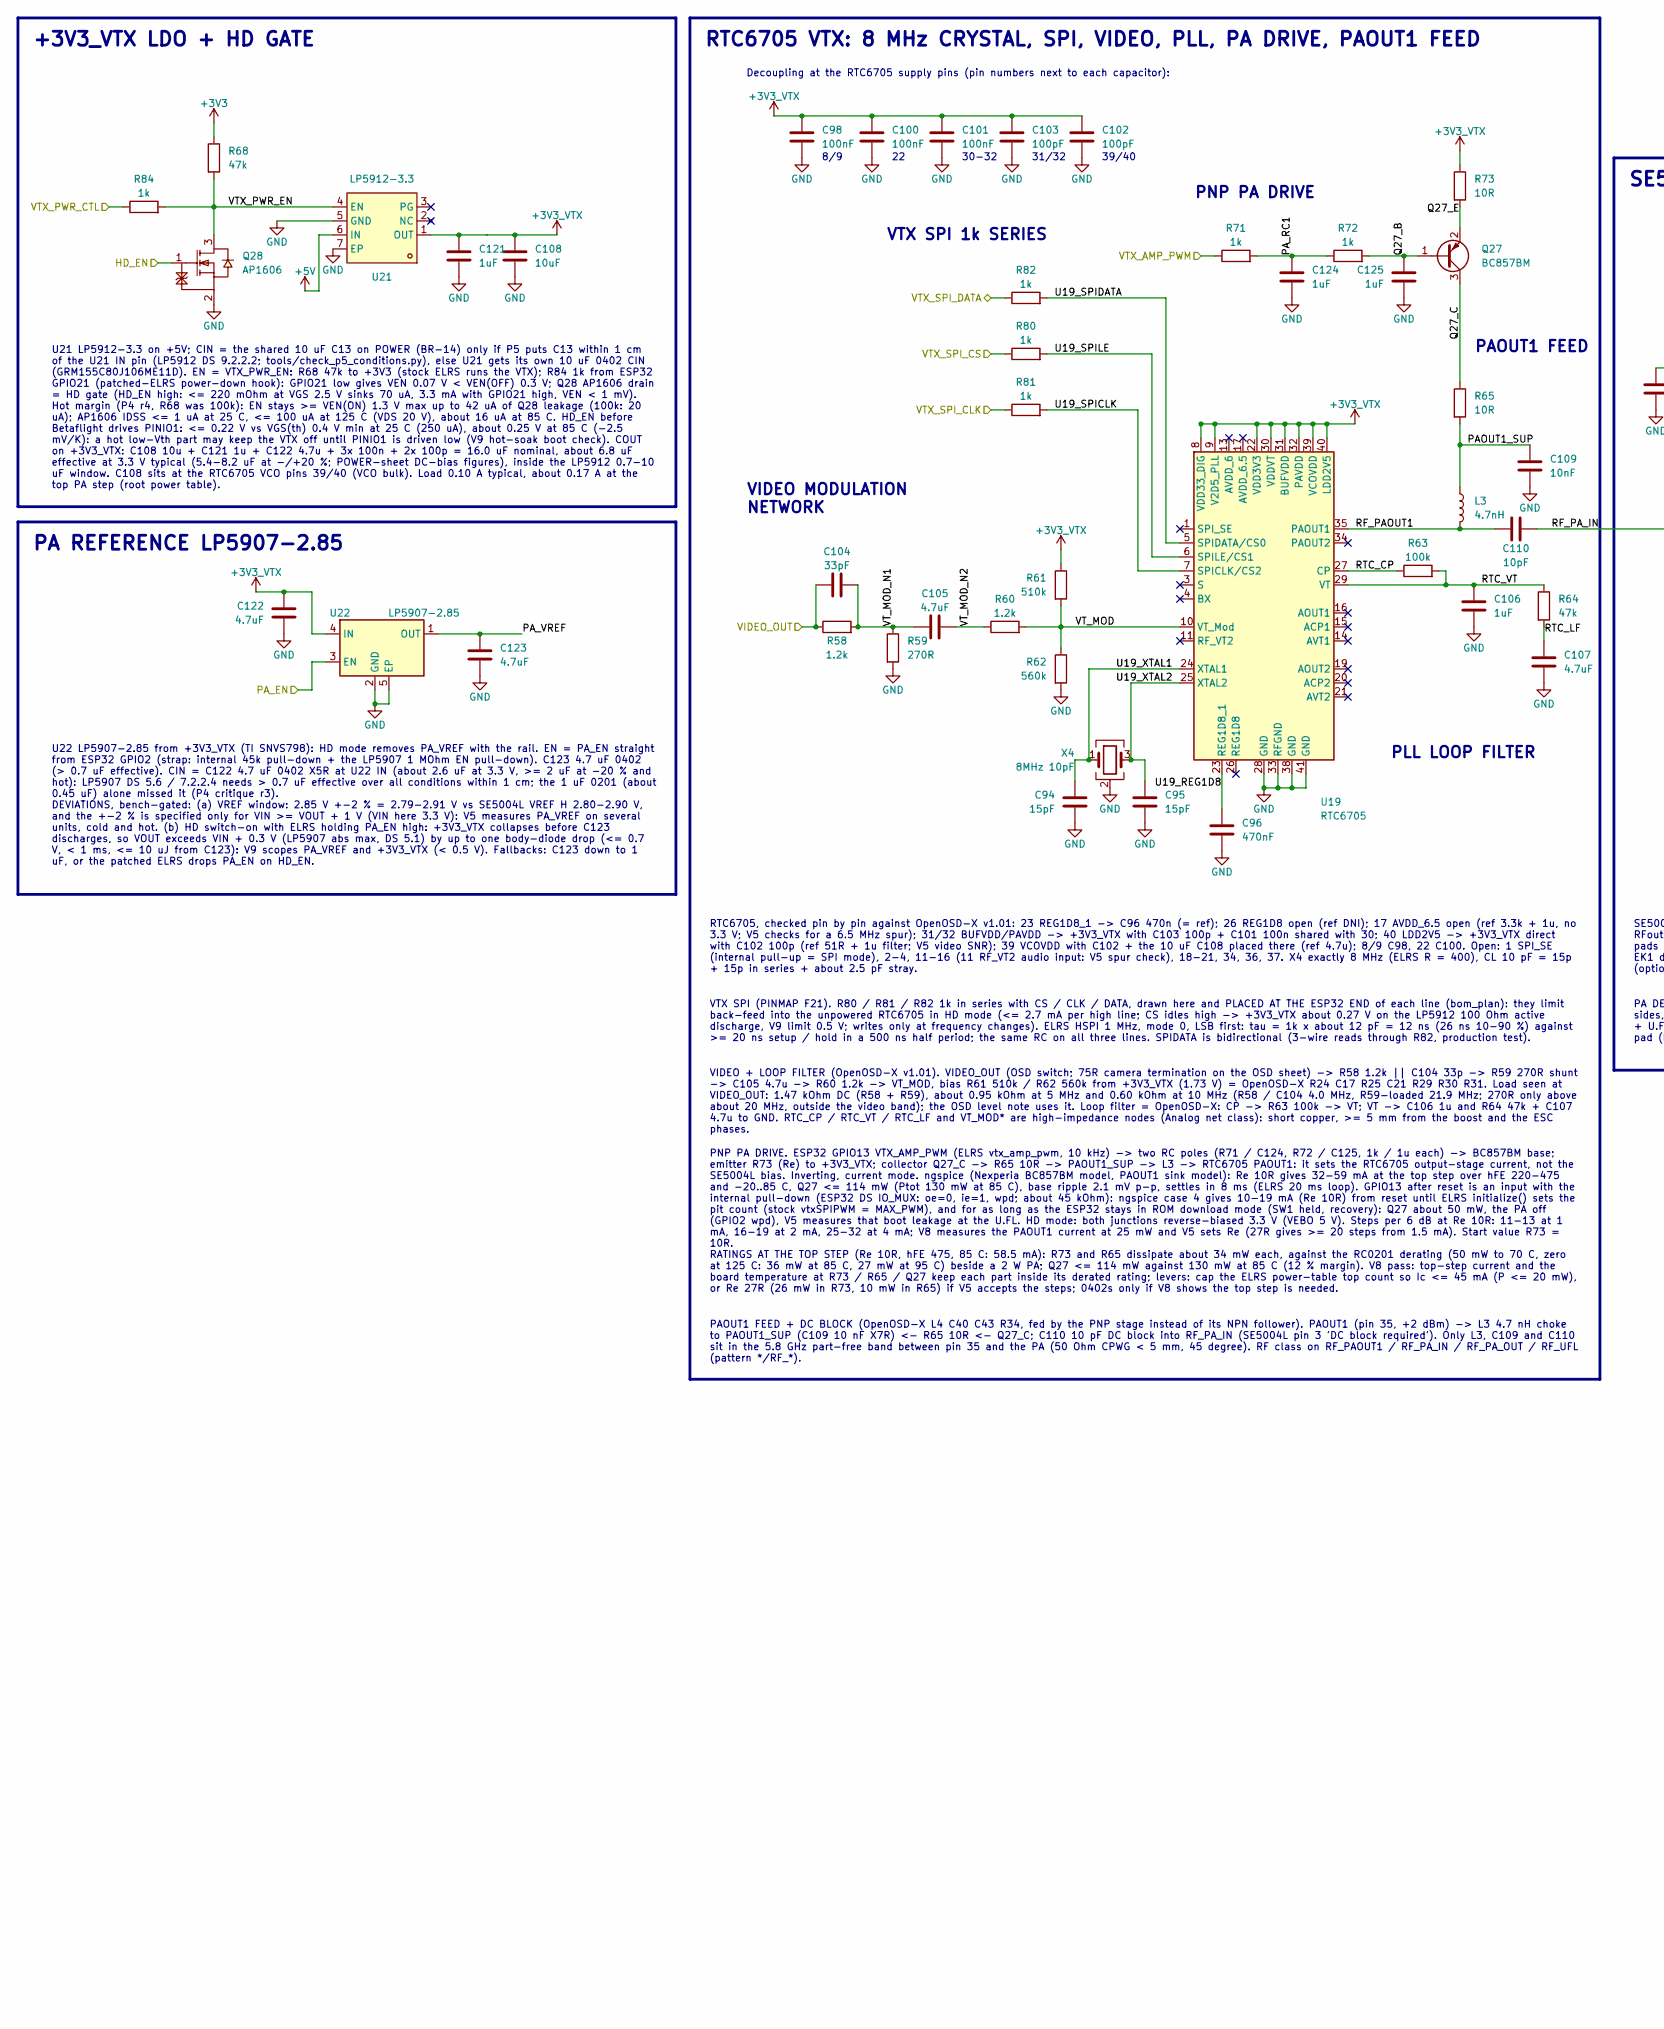
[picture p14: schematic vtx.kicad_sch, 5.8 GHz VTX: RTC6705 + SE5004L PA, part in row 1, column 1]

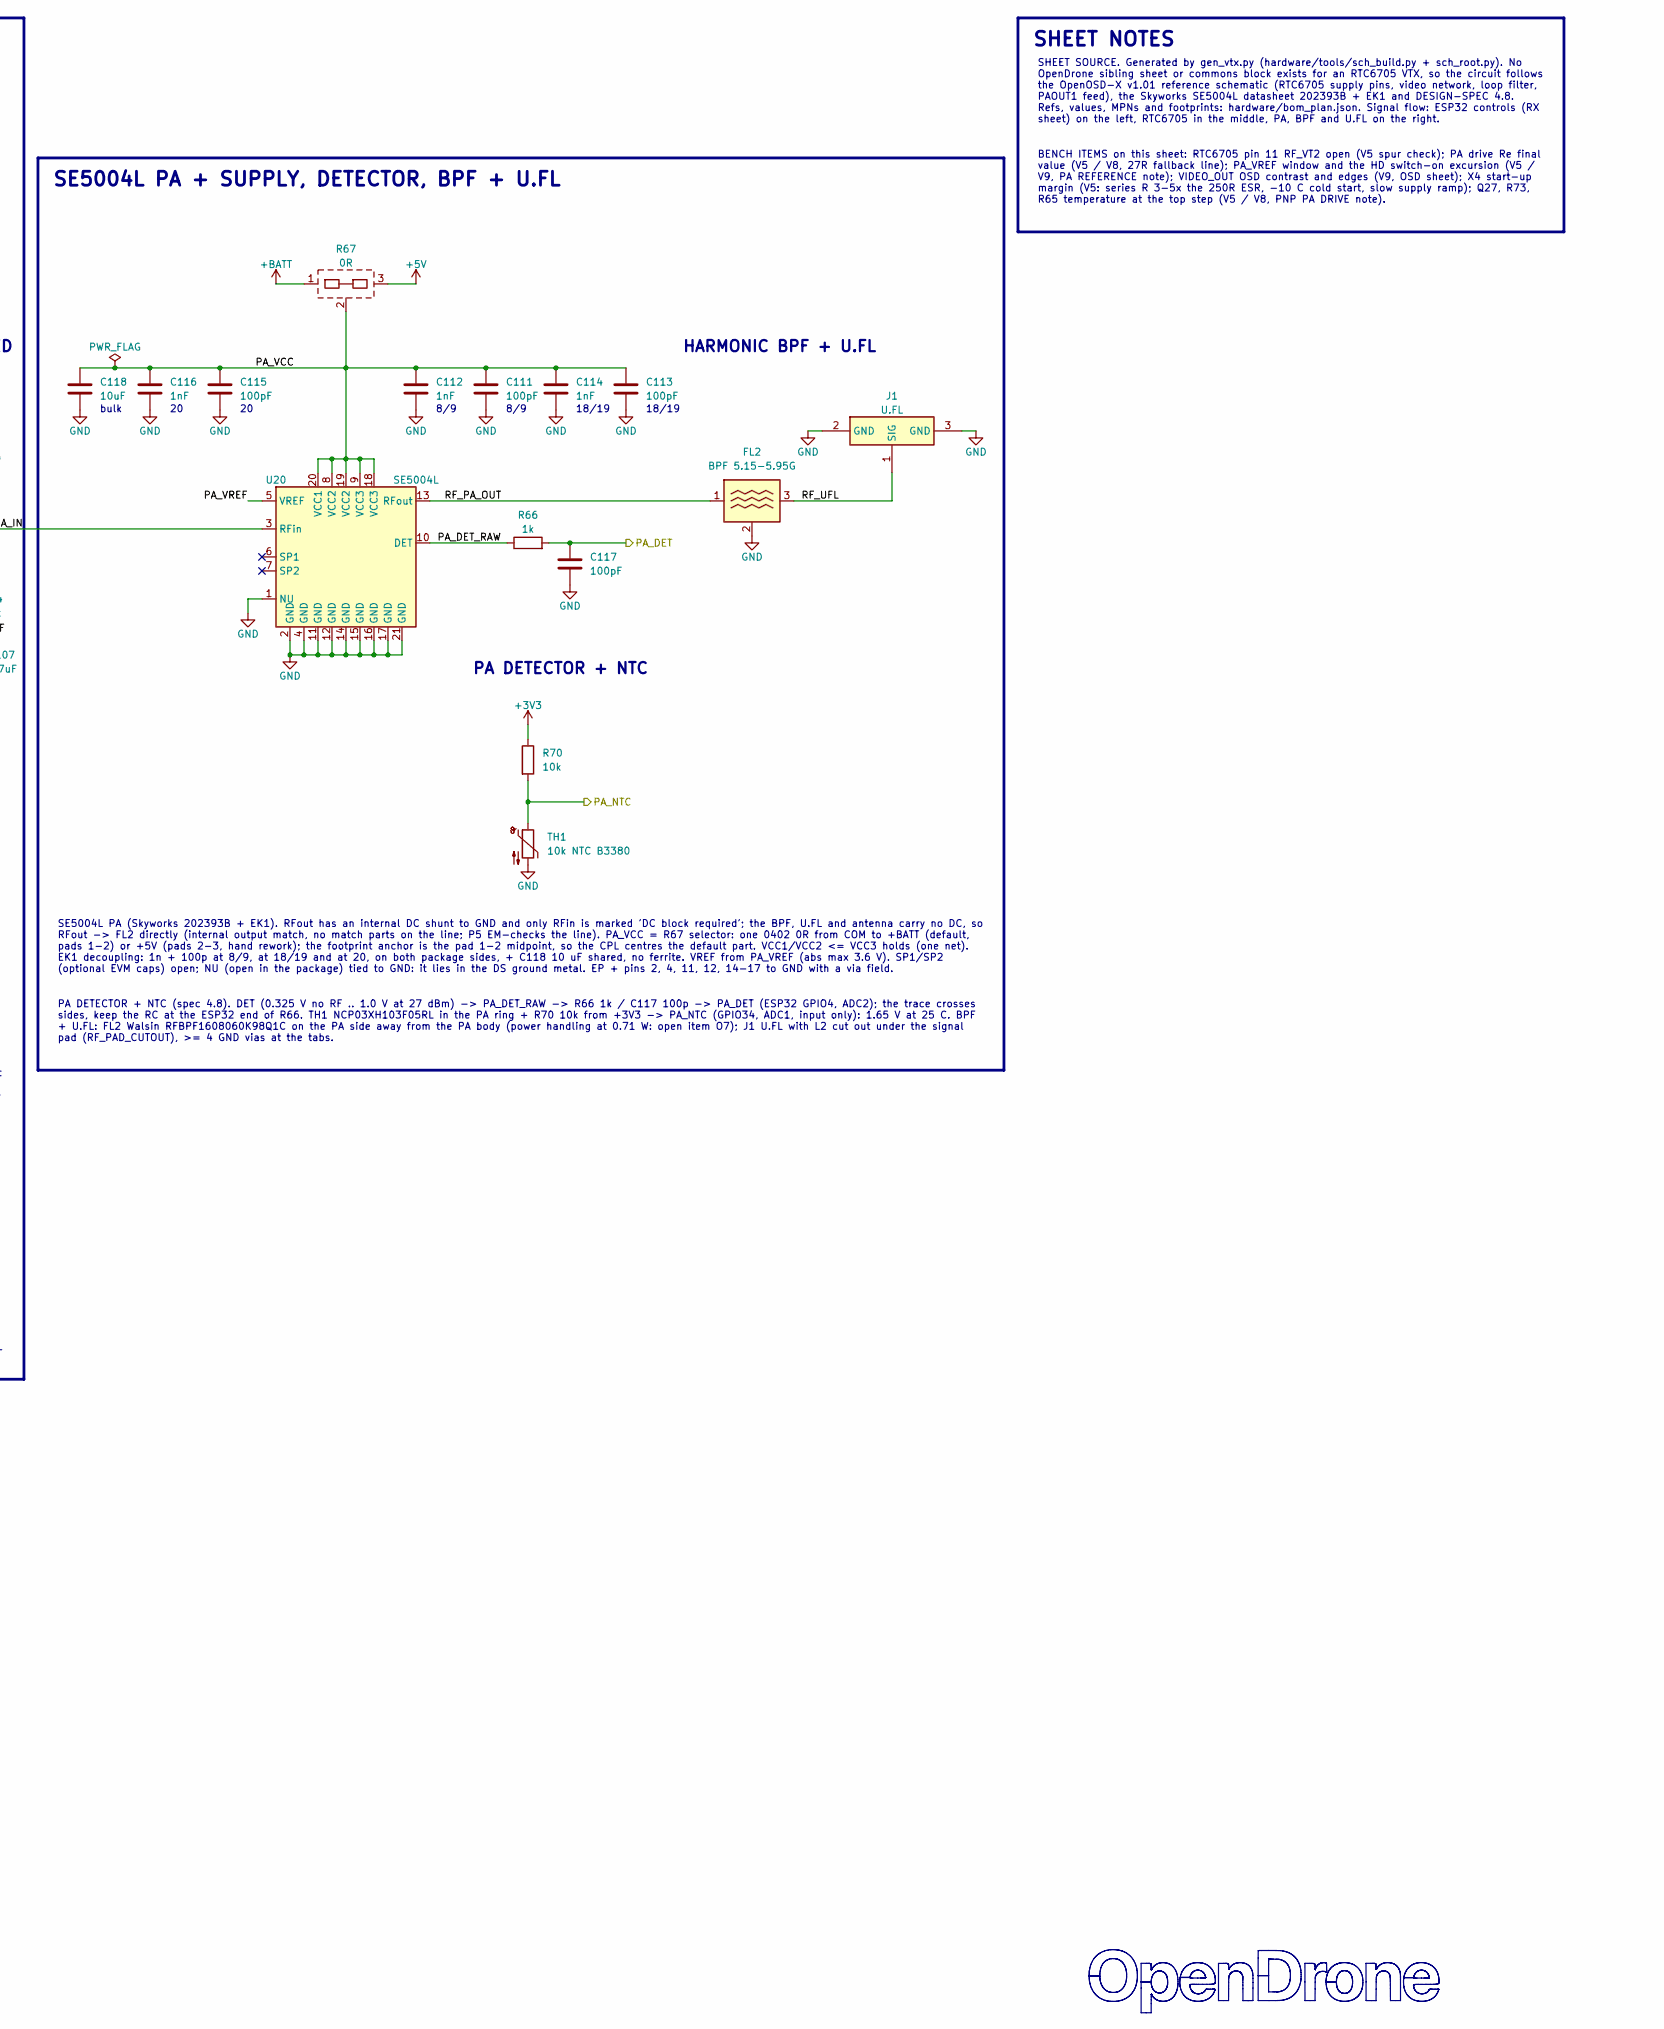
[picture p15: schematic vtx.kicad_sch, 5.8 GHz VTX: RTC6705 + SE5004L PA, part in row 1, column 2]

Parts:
C94, C95: 15pF; C_0201_0603Metric_W; MPN GRM0335C1H150JA01D; LCSC C85891
C96: 470nF; C_0201_0603Metric_W; MPN GRM033R60J474KE90D; LCSC C85926
C98, C100, C101: 100nF; C_0201_0603Metric_W; MPN GRM033C81E104KE14D; LCSC C181047
C102, C103, C111, C113, C115, C117: 100pF; C_0201_0603Metric_W; MPN GRM0335C1H101JA01D
C104: 33pF; C_0201_0603Metric_W; MPN GRM0335C1H330JA01D
C105, C107, C122, C123: 4.7uF; C_0402_1005Metric_W; MPN CL05A475MP5NRNC; LCSC C23733
C106: 1uF; C_0402_1005Metric_W; MPN CL05A105KA5NQNC; LCSC C52923
C108, C118: 10uF; C_0402_1005Metric_W; MPN GRM155C80J106ME11D; LCSC C237279
C109: 10nF; C_0201_0603Metric_W; MPN GRM033R71A103KA01D; LCSC C76941
C110: 10pF; C_0201_0603Metric_W; MPN GRM0335C1H100JA01D; LCSC C76921
C112, C114, C116: 1nF; C_0201_0603Metric_W; MPN GRM033R71H102KA12D; LCSC C85934
C121, C124, C125: 1uF; C_0201_0603Metric_W; MPN GRM033R61A105ME44D; LCSC C76935
FL2: BPF 5.15-5.95G; Walsin_RFBPF1608060K98Q1C; MPN RFBPF1608060K98Q1C; LCSC C2442150
J1: U.FL; U.FL_Hirose_U.FL-R-SMT-1_Vertical; MPN U.FL-R-SMT-1(80); LCSC C88374
L3: 4.7nH; L_0201_0603Metric_W; MPN LQP03TN4N7H02D; LCSC C86126
Q27: BC857BM; DFN-3L_L1.0-W0.6-P0.65-BR_W; MPN BC857BM,315; LCSC C549525
Q28: AP1606; DFN-3L_L1.0-W0.6-P0.65-BR_W; MPN AP1606; LCSC C2849580
R58, R60: 1.2k; R_0201_0603Metric_W; MPN RC0201FR-071K2L
R59: 270R; R_0201_0603Metric_W; MPN RC0201FR-07270RL
R61: 510k; R_0201_0603Metric_W; MPN RC0201FR-07510KL
R62: 560k; R_0201_0603Metric_W; MPN RC0201FR-07560KL
R63: 100k; R_0201_0603Metric_W; MPN RC0201FR-07100KL; LCSC C106224
R64, R68: 47k; R_0201_0603Metric_W; MPN RC0201FR-0747KL
R65, R73: 10R; R_0201_0603Metric_W; MPN RC0201FR-0710RL; LCSC C106226
R66, R71, R72, R80, R81, R82, R84: 1k; R_0201_0603Metric_W; MPN RC0201FR-071KL
R67: 0R; R_0402_Selector_3Pad; MPN RC0402JR-070RL; LCSC C60485
R70: 10k; R_0201_0603Metric_W; MPN RC0201FR-0710KL; LCSC C106225
TH1: 10k NTC B3380; R_0201_0603Metric_W; MPN NCP03XH103F05RL; LCSC C98098
U19: RTC6705; QFN-40_6x6mm_P0.5mm_EP_RTC6705_Dense; MPN RTC6705; LCSC C913074
U20: SE5004L; QFN-20_4x4mm_P0.5mm_EP_SE5004L; MPN SE5004L-R; LCSC C210263
U21: LP5912-3.3; WSON-6-1EP_2x2mm_P0.65mm_EP1x1.6mm_Dense; MPN LP5912-3.3DRVR; LCSC C524780
U22: LP5907-2.85; X2SON-4_L1.0-W1.0-P0.65-TL-EP_Dense; MPN LP5907SNX-2.85/NOPB
X4: 8MHz 10pF; CRYSTAL-SMD_4P-L3.2-W2.5-BL_Dense; MPN TAXM8M4RDBCCT2T; LCSC C400090

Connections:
+3V3: R68.1, R70.1; also elsewhere on the board
+3V3_VTX: C98.1, C100.1, C101.1, C102.1, C103.1, C108.1, C121.1, C122.1, R61.1, R73.1, U19.8 (VDD33_DIG), U19.9 (V2D5_PLL), U19.22 (VDD3V3), U19.30 (VDDVT), U19.31 (BUFVDD), U19.32 (PAVDD), U19.39 (VCOVDD), U19.40 (LDD2V5), U21.1 (OUT), U22.4 (IN)
+5V: R67.3 (B), U21.6 (IN); also elsewhere on the board
+BATT: R67.1 (A); also elsewhere on the board
/HD_EN: Q28.1 (G); also elsewhere on the board
/PA_DET: C117.1, R66.2; also elsewhere on the board
/PA_EN: U22.3 (EN); also elsewhere on the board
/PA_NTC: R70.2, TH1.1; also elsewhere on the board
/VIDEO_OUT: C104.1, R58.1; also elsewhere on the board
/VTX/PAOUT1_SUP: C109.1, L3.1, R65.2
/VTX/PA_DET_RAW: R66.1, U20.10 (DET)
/VTX/PA_RC1: C124.1, R71.2, R72.1
/VTX/PA_VCC: C111.1, C112.1, C113.1, C114.1, C115.1, C116.1, C118.1, R67.2 (COM), U20.8 (VCC2), U20.9 (VCC3), U20.18 (VCC3), U20.19 (VCC2), U20.20 (VCC1)
/VTX/PA_VREF: C123.1, U20.5 (VREF), U22.1 (OUT)
/VTX/Q27_B: C125.1, Q27.1 (B), R72.2
/VTX/Q27_C: Q27.3 (C), R65.1
/VTX/Q27_E: Q27.2 (E), R73.2
/VTX/RF_PAOUT1: C110.1, L3.2, U19.35 (PAOUT1)
/VTX/RF_PA_IN: C110.2, U20.3 (RFin)
/VTX/RF_PA_OUT: FL2.1 (IN), U20.13 (RFout)
/VTX/RF_UFL: FL2.3 (OUT), J1.1 (SIG)
/VTX/RTC_CP: R63.1, U19.27 (CP)
/VTX/RTC_LF: C107.1, R64.2
/VTX/RTC_VT: C106.1, R63.2, R64.1, U19.29 (VT)
/VTX/U19_REG1D8: C96.1, U19.23 (REG1D8_1)
/VTX/U19_SPICLK: R81.2, U19.7 (SPICLK/CS2)
/VTX/U19_SPIDATA: R82.2, U19.5 (SPIDATA/CS0)
/VTX/U19_SPILE: R80.2, U19.6 (SPILE/CS1)
/VTX/U19_XTAL1: C94.1, U19.24 (XTAL1), X4.1
/VTX/U19_XTAL2: C95.1, U19.25 (XTAL2), X4.3
/VTX/VTX_PWR_EN: Q28.3 (D), R68.2, R84.2, U21.4 (EN)
/VTX/VT_MOD: R60.2, R61.2, R62.1, U19.10 (VT_Mod)
/VTX/VT_MOD_N1: C104.2, C105.1, R58.2, R59.1
/VTX/VT_MOD_N2: C105.2, R60.1
/VTX_AMP_PWM: R71.1; also elsewhere on the board
/VTX_PWR_CTL: R84.1; also elsewhere on the board
/VTX_SPI_CLK: R81.1; also elsewhere on the board
/VTX_SPI_CS: R80.1; also elsewhere on the board
/VTX_SPI_DATA: R82.1; also elsewhere on the board
GND: C94.2, C95.2, C96.2, C98.2, C100.2, C101.2, C102.2, C103.2, C106.2, C107.2, C108.2, C109.2, C111.2, C112.2, C113.2, C114.2, C115.2, C116.2, C117.2, C118.2, C121.2, C122.2, C123.2, C124.2, C125.2, FL2.2 (GND), J1.2 (GND), J1.3 (GND), Q28.2 (S), R59.2, R62.2, TH1.2, U19.28 (GND), U19.33 (RFGND), U19.38 (GND), U19.41 (GND), U20.1 (NU), U20.2 (GND), U20.4 (GND), U20.11 (GND), U20.12 (GND), U20.14 (GND), U20.15 (GND), U20.16 (GND), U20.17 (GND), U20.21 (GND), U21.5 (GND), U21.7 (EP), U22.2 (GND), U22.5 (EP), X4.2 (G), X4.4 (G); also elsewhere on the board

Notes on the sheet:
VIDEO MODULATION NETWORK
18/19
39/40
8/9
RTC6705 VTX: 8 MHz CRYSTAL, SPI, VIDEO, PLL, PA DRIVE, PAOUT1 FEED
SE5004L PA + SUPPLY, DETECTOR, BPF + U.FL
+3V3_VTX LDO + HD GATE
HARMONIC BPF + U.FL
bulk
PA DETECTOR + NTC
SHEET NOTES
PLL LOOP FILTER
Decoupling at the RTC6705 supply pins (pin numbers next to each capacitor):
PNP PA DRIVE
VTX SPI 1k SERIES
PAOUT1 FEED
31/32
PA REFERENCE LP5907-2.85
30-32
U22 LP5907-2.85 from +3V3_VTX (TI SNVS798): HD mode removes PA_VREF with the rail. EN = PA_EN straight from ESP32 GPIO2 (strap: internal 45k pull-down + the LP5907 1 MOhm EN pull-down). C123 4.7 uF 0402 (> 0.7 uF effective). CIN = C122 4.7 uF 0402 X5R at U22 IN (about 2.6 uF at 3.3 V, >= 2 uF at -2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
U21 LP5912-3.3 on +5V; CIN = the shared 10 uF C13 on POWER (BR-14) only if P5 puts C13 within 1 cm of the U21 IN pin (LP5912 DS 9.2.2.2; tools/check_p5_conditions.py), else U21 gets its own 10 uF 0402 CIN (GRM155C80J106ME11D). EN = VTX_PWR_EN: R68 47k to +3V3 (stock ELRS runs the VTX); R84 1k from 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
PA DETECTOR + NTC (spec 4.8). DET (0.325 V no RF .. 1.0 V at 27 dBm) -> PA_DET_RAW -> R66 1k / C117 100p -> PA_DET (ESP32 GPIO4, ADC2); the trace crosses sides, keep the RC at the ESP32 end of R66. TH1 NCP03XH103F05RL in the PA ring + R70 10k from +3V3 -> PA_NTC (GPIO34, ADC1, input only): 1.65 V a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
SE5004L PA (Skyworks 202393B + EK1). RFout has an internal DC shunt to GND and only RFin is marked 'DC block required'; the BPF, U.FL and antenna carry no DC, so RFout -> FL2 directly (internal output match, no match parts on the line; P5 EM-checks the line). PA_VCC = R67 selector: one 0402 0R from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
VIDEO + LOOP FILTER (OpenOSD-X v1.01). VIDEO_OUT (OSD switch; 75R camera termination on the OSD sheet) -> R58 1.2k || C104 33p -> R59 270R shunt -> C105 4.7u -> R60 1.2k -> VT_MOD, bias R61 510k / R62 560k from +3V3_VTX (1.73 V) = OpenOSD-X R24 C17 R25 C21 R29 R30 R31. Load seen at VIDEO_OUT: 1.47 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
PNP PA DRIVE. ESP32 GPIO13 VTX_AMP_PWM (ELRS vtx_amp_pwm, 10 kHz) -> two RC poles (R71 / C124, R72 / C125, 1k / 1u each) -> BC857BM base; emitter R73 (Re) to +3V3_VTX; collector Q27_C -> R65 10R -> PAOUT1_SUP -> L3 -> RTC6705 PAOUT1: it sets the RTC6705 output-stage current, not the SE5004L bias. I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
RTC6705, checked pin by pin against OpenOSD-X v1.01: 23 REG1D8_1 -> C96 470n (= ref); 26 REG1D8 open (ref DNI); 17 AVDD_6.5 open (ref 3.3k + 1u, no 3.3 V; V5 checks for a 6.5 MHz spur); 31/32 BUFVDD/PAVDD -> +3V3_VTX with C103 100p + C101 100n shared with 30; 40 LDD2V5 -> +3V3_VTX direct with C102 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
PAOUT1 FEED + DC BLOCK (OpenOSD-X L4 C40 C43 R34, fed by the PNP stage instead of its NPN follower). PAOUT1 (pin 35, +2 dBm) -> L3 4.7 nH choke to PAOUT1_SUP (C109 10 nF X7R) <- R65 10R <- Q27_C; C110 10 pF DC block into RF_PA_IN (SE5004L pin 3 'DC block required'). Only L3, C109 and C110 sit in th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
VTX SPI (PINMAP F21). R80 / R81 / R82 1k in series with CS / CLK / DATA, drawn here and PLACED AT THE ESP32 END of each line (bom_plan): they limit back-feed into the unpowered RTC6705 in HD mode (<= 2.7 mA per high line; CS idles high -> +3V3_VTX about 0.27 V on the LP5912 100 Ohm active discharge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
SHEET SOURCE. Generated by gen_vtx.py (hardware/tools/sch_build.py + sch_root.py). No OpenDrone sibling sheet or commons block exists for an RTC6705 VTX, so the circuit follows the OpenOSD-X v1.01 reference schematic (RTC6705 supply pins, video network, loop filter, PAOUT1 feed), the Skyworks SE500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
BENCH ITEMS on this sheet: RTC6705 pin 11 RF_VT2 open (V5 spur check); PA drive Re final value (V5 / V8, 27R fallback line); PA_VREF window and the HD switch-on excursion (V5 / V9, PA REFERENCE note); VIDEO_OUT OSD contrast and edges (V9, OSD sheet); X4 start-up margin (V5: series R 3-5x the 250R E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

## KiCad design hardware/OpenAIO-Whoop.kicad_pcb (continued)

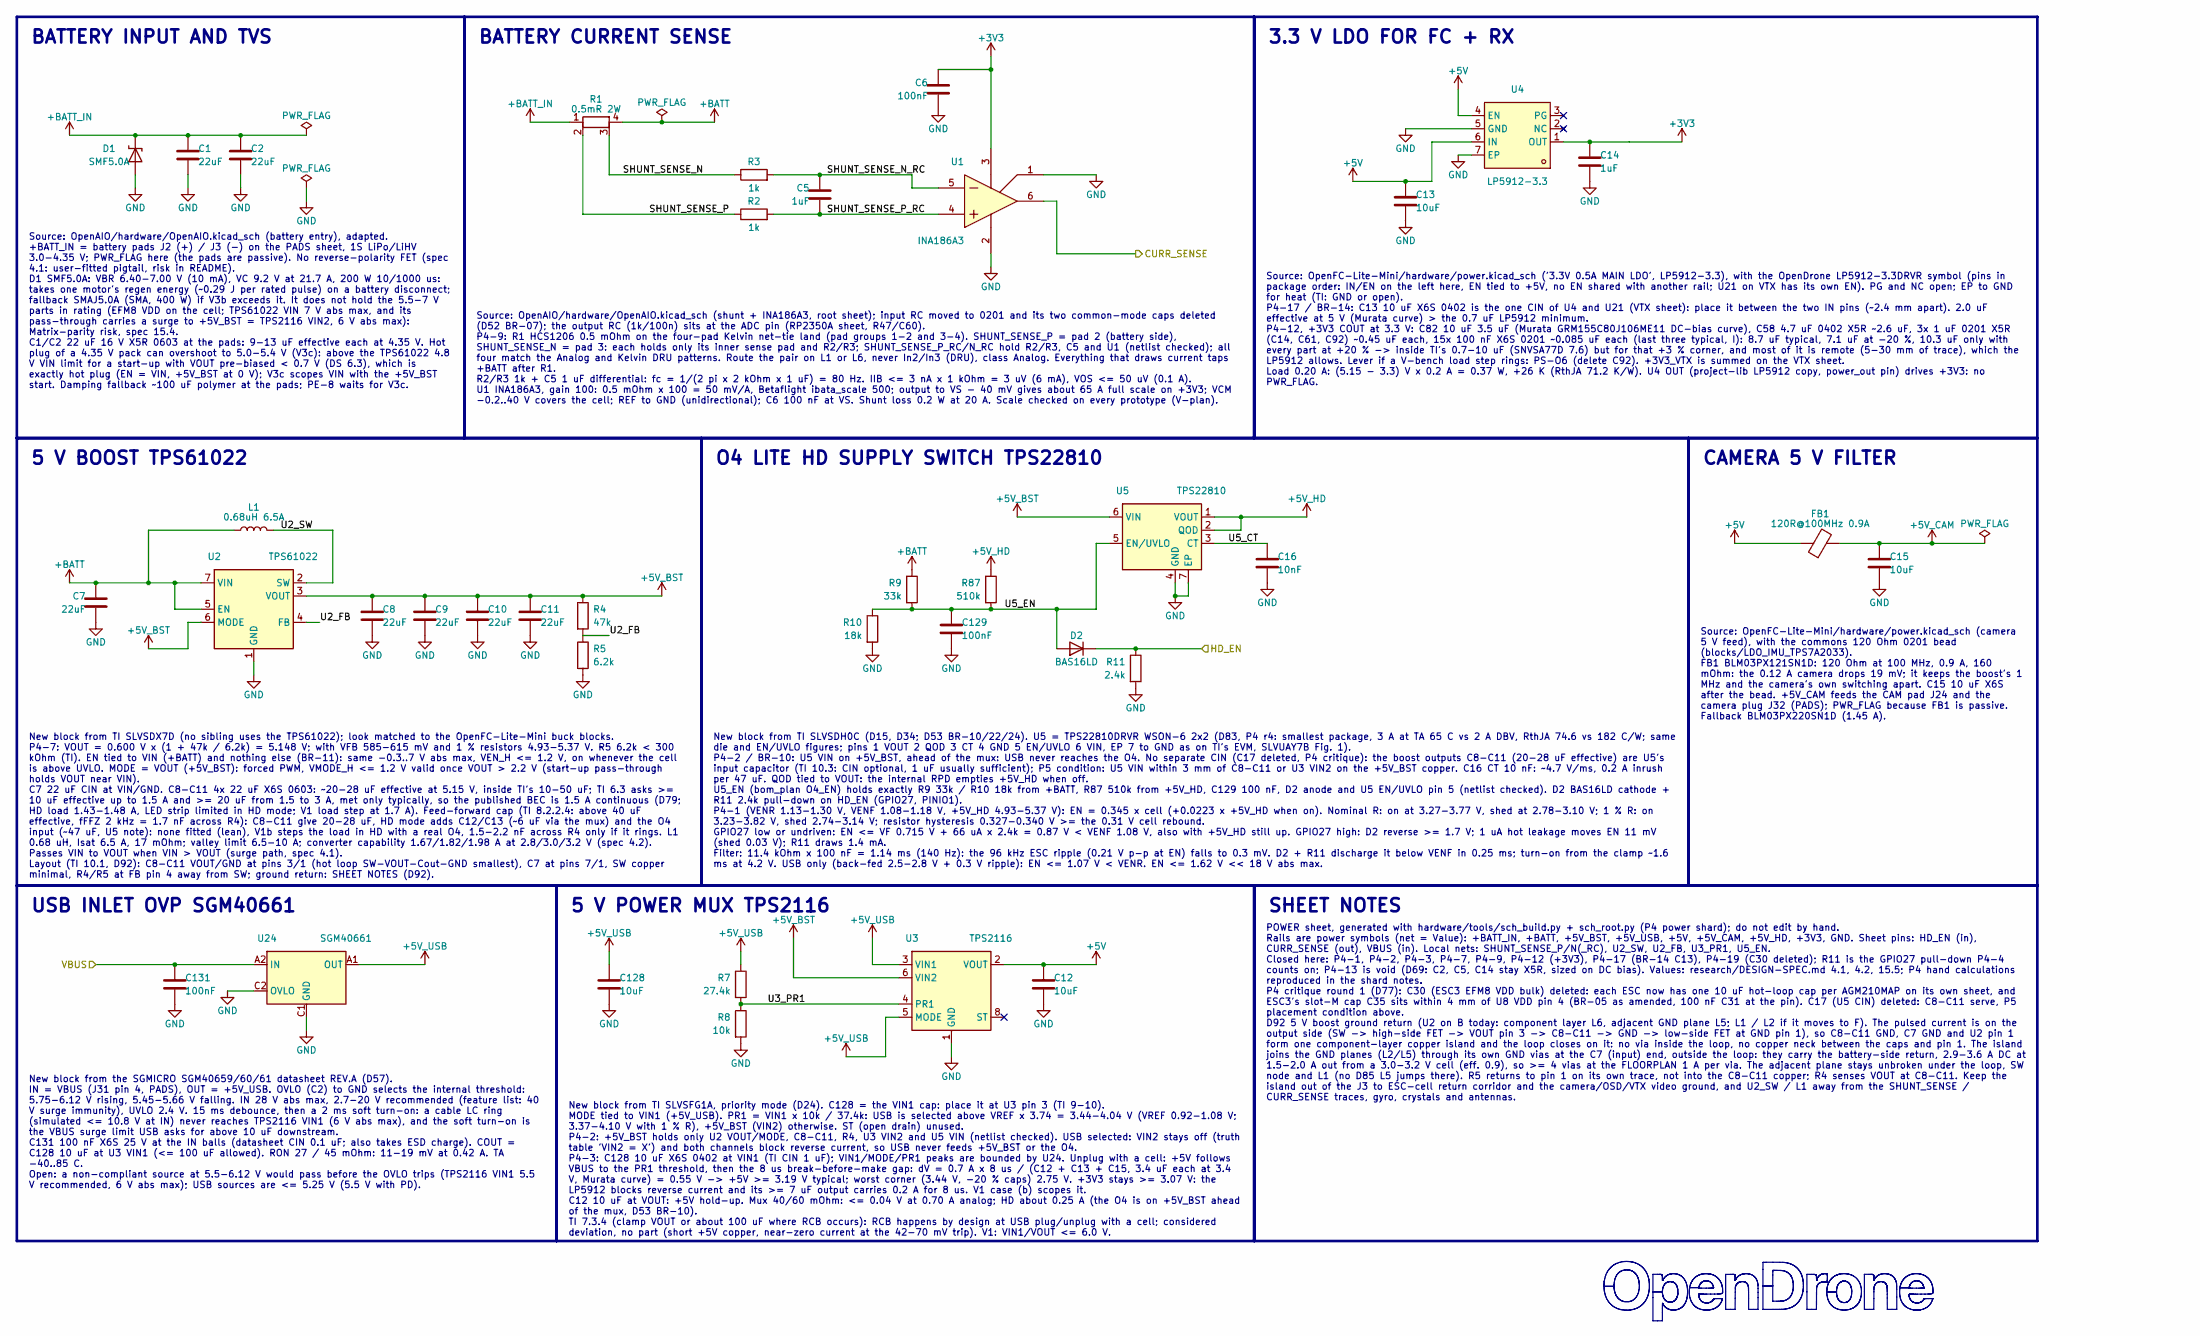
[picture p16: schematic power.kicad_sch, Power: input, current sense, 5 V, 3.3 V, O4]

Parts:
C1, C2: 22uF; C_0603_1608Metric_W; MPN CL10A226MO7JZNC; LCSC C2762594
C5, C14: 1uF; C_0201_0603Metric_W; MPN GRM033R61A105ME44D; LCSC C76935
C6, C129, C131: 100nF; C_0201_0603Metric_W; MPN GRM033C81E104KE14D; LCSC C181047
C7, C8, C9, C10, C11: 22uF; C_0603_1608Metric_W; MPN GRM188C80J226ME15D; LCSC C393031
C12, C13, C15, C128: 10uF; C_0402_1005Metric_W; MPN GRM155C80J106ME11D; LCSC C237279
C16: 10nF; C_0201_0603Metric_W; MPN GRM033R71A103KA01D; LCSC C76941
D1: SMF5.0A; SOD-123FL_L2.7-W1.8-LS3.7-RD_Dense; MPN SMF5.0A; LCSC C151296
D2: BAS16LD; Nexperia_SOD882D; MPN BAS16LD,315; LCSC C841775
FB1: 120R@100MHz 0.9A; L_0201_0603Metric_W; MPN BLM03PX121SN1D
L1: 0.68uH 6.5A; IND-SMD_L2.5-W2.0_FTC252012; MPN FTC252012SR68MBCA; LCSC C5832369
R1: 0.5mR 2W; R_1206_Kelvin_4Pad_NetTie_HCS1206_Dense; MPN HCS1206FTL500; LCSC C346511
R2, R3: 1k; R_0201_0603Metric_W; MPN RC0201FR-071KL
R4: 47k; R_0201_0603Metric_W; MPN RC0201FR-0747KL
R5: 6.2k; R_0201_0603Metric_W; MPN RC0201FR-076K2L
R7: 27.4k; R_0201_0603Metric_W; MPN RC0201FR-0727K4L
R8: 10k; R_0201_0603Metric_W; MPN RC0201FR-0710KL; LCSC C106225
R9: 33k; R_0201_0603Metric_W; MPN RC0201FR-0733KL
R10: 18k; R_0201_0603Metric_W; MPN RC0201FR-0718KL
R11: 2.4k; R_0201_0603Metric_W; MPN RTT012401FTH; LCSC C166281
R87: 510k; R_0201_0603Metric_W; MPN RC0201FR-07510KL
U1: INA186A3; SOT-363_SC-70-6_Dense; MPN INA186A3IDCKR; LCSC C2058245
U2: TPS61022; TI_VQFN-HR-7_2x2mm_RWU; MPN TPS61022RWUR; LCSC C915088
U3: TPS2116; TI_SOT-583_DRL; MPN TPS2116DRLR; LCSC C3235557
U4: LP5912-3.3; WSON-6-1EP_2x2mm_P0.65mm_EP1x1.6mm_Dense; MPN LP5912-3.3DRVR; LCSC C524780
U5: TPS22810; WSON-6-1EP_2x2mm_P0.65mm_EP1x1.6mm_Dense; MPN TPS22810DRVR
U24: SGM40661; WLCSP-6_L1.30-W0.94-P0.40_SGM40661; MPN SGM40661YG/TR

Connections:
+3V3: C6.1, C14.1, U1.3 (VS), U4.1 (OUT); also elsewhere on the board
+5V: C12.1, C13.1, FB1.1, U3.2 (VOUT), U3.7 (VOUT), U4.4 (EN), U4.6 (IN); also elsewhere on the board
+5V_BST: C8.1, C9.1, C10.1, C11.1, R4.1, U2.3 (VOUT), U2.6 (MODE), U3.6 (VIN2), U5.6 (VIN)
+5V_CAM: C15.1, FB1.2; also elsewhere on the board
+5V_HD: R87.1, U5.1 (VOUT), U5.2 (QOD); also elsewhere on the board
+5V_USB: C128.1, R7.1, U3.3 (VIN1), U3.5 (MODE), U24.A1 (OUT), U24.B1 (OUT)
+BATT: C7.1, L1.1, R1.4, R9.1, U2.5 (EN), U2.7 (VIN); also elsewhere on the board
+BATT_IN: C1.1, C2.1, D1.1 (K), R1.1; also elsewhere on the board
/CURR_SENSE: U1.6 (OUT); also elsewhere on the board
/HD_EN: D2.1 (K), R11.1; also elsewhere on the board
/POWER/SHUNT_SENSE_N: R1.3, R3.1
/POWER/SHUNT_SENSE_N_RC: C5.1, R3.2, U1.5 (-IN)
/POWER/SHUNT_SENSE_P: R1.2, R2.1
/POWER/SHUNT_SENSE_P_RC: C5.2, R2.2, U1.4 (+IN)
/POWER/U2_FB: R4.2, R5.1, U2.4 (FB)
/POWER/U2_SW: L1.2, U2.2 (SW)
/POWER/U3_PR1: R7.2, R8.1, U3.4 (PR1)
/POWER/U5_CT: C16.1, U5.3 (CT)
/POWER/U5_EN: C129.1, D2.2 (A), R9.2, R10.1, R87.2, U5.5 (EN/UVLO)
/VBUS: C131.1, U24.A2 (IN), U24.B2 (IN); also elsewhere on the board
GND: C1.2, C2.2, C6.2, C7.2, C8.2, C9.2, C10.2, C11.2, C12.2, C13.2, C14.2, C15.2, C16.2, C128.2, C129.2, C131.2, D1.2 (A), R5.2, R8.2, R10.2, R11.2, U1.1 (REF), U1.2 (GND), U2.1 (GND), U3.1 (GND), U4.5 (GND), U4.7 (EP), U5.4 (GND), U5.7 (EP), U24.C1 (GND), U24.C2 (OVLO); also elsewhere on the board

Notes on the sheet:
SHEET NOTES
O4 LITE HD SUPPLY SWITCH TPS22810
5 V BOOST TPS61022
BATTERY CURRENT SENSE
3.3 V LDO FOR FC + RX
USB INLET OVP SGM40661
CAMERA 5 V FILTER
5 V POWER MUX TPS2116
BATTERY INPUT AND TVS
Source: OpenFC-Lite-Mini/hardware/power.kicad_sch (camera 5 V feed), with the commons 120 Ohm 0201 bead (blocks/LDO_IMU_TPS7A2033). FB1 BLM03PX121SN1D: 120 Ohm at 100 MHz, 0.9 A, 160 mOhm: the 0.12 A camera drops 19 mV; it keeps the boost's 1 MHz and the camera's own switching apart. C15 10 uF X6S 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
POWER sheet, generated with hardware/tools/sch_build.py + sch_root.py (P4 power shard); do not edit by hand. Rails are power symbols (net = Value): +BATT_IN, +BATT, +5V_BST, +5V_USB, +5V, +5V_CAM, +5V_HD, +3V3, GND. Sheet pins: HD_EN (in), CURR_SENSE (out), VBUS (in). Local nets: SHUNT_SENSE_P/N(_R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
Source: OpenAIO/hardware/OpenAIO.kicad_sch (battery entry), adapted. +BATT_IN = battery pads J2 (+) / J3 (-) on the PADS sheet, 1S LiPo/LiHV 3.0-4.35 V; PWR_FLAG here (the pads are passive). No reverse-polarity FET (spec 4.1: user-fitted pigtail, risk in README). D1 SMF5.0A: VBR 6.40-7.00 V (10 mA)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
New block from TI SLVSFG1A, priority mode (D24). C128 = the VIN1 cap: place it at U3 pin 3 (TI 9-10). MODE tied to VIN1 (+5V_USB). PR1 = VIN1 x 10k / 37.4k: USB is selected above VREF x 3.74 = 3.44-4.04 V (VREF 0.92-1.08 V; 3.37-4.10 V with 1 % R), +5V_BST (VIN2) otherwise. ST (open drain) unused. 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
New block from TI SLVSDX7D (no sibling uses the TPS61022); look matched to the OpenFC-Lite-Mini buck blocks. P4-7: VOUT = 0.600 V x (1 + 47k / 6.2k) = 5.148 V; with VFB 585-615 mV and 1 % resistors 4.93-5.37 V. R5 6.2k < 300 kOhm (TI). EN tied to VIN (+BATT) and nothing else (BR-11): same -0.3..7 V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
Source: OpenAIO/hardware/OpenAIO.kicad_sch (shunt + INA186A3, root sheet); input RC moved to 0201 and its two common-mode caps deleted (D52 BR-07); the output RC (1k/100n) sits at the ADC pin (RP2350A sheet, R47/C60). P4-9: R1 HCS1206 0.5 mOhm on the four-pad Kelvin net-tie land (pad groups 1-2 and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
Source: OpenFC-Lite-Mini/hardware/power.kicad_sch ('3.3V 0.5A MAIN LDO', LP5912-3.3), with the OpenDrone LP5912-3.3DRVR symbol (pins in package order: IN/EN on the left here, EN tied to +5V, no EN shared with another rail; U21 on VTX has its own EN). PG and NC open; EP to GND for heat (TI: GND or o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
New block from the SGMICRO SGM40659/60/61 datasheet REV.A (D57). IN = VBUS (J31 pin 4, PADS), OUT = +5V_USB. OVLO (C2) to GND selects the internal threshold: 5.75-6.12 V rising, 5.45-5.66 V falling. IN 28 V abs max, 2.7-20 V recommended (feature list: 40 V surge immunity), UVLO 2.4 V. 15 ms debounc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
New block from TI SLVSDH0C (D15, D34; D53 BR-10/22/24). U5 = TPS22810DRVR WSON-6 2x2 (D83, P4 r4: smallest package, 3 A at TA 65 C vs 2 A DBV, RthJA 74.6 vs 182 C/W; same die and EN/UVLO figures; pins 1 VOUT 2 QOD 3 CT 4 GND 5 EN/UVLO 6 VIN, EP 7 to GND as on TI's EVM, SLVUAY7B Fig. 1). P4-2 / BR-1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

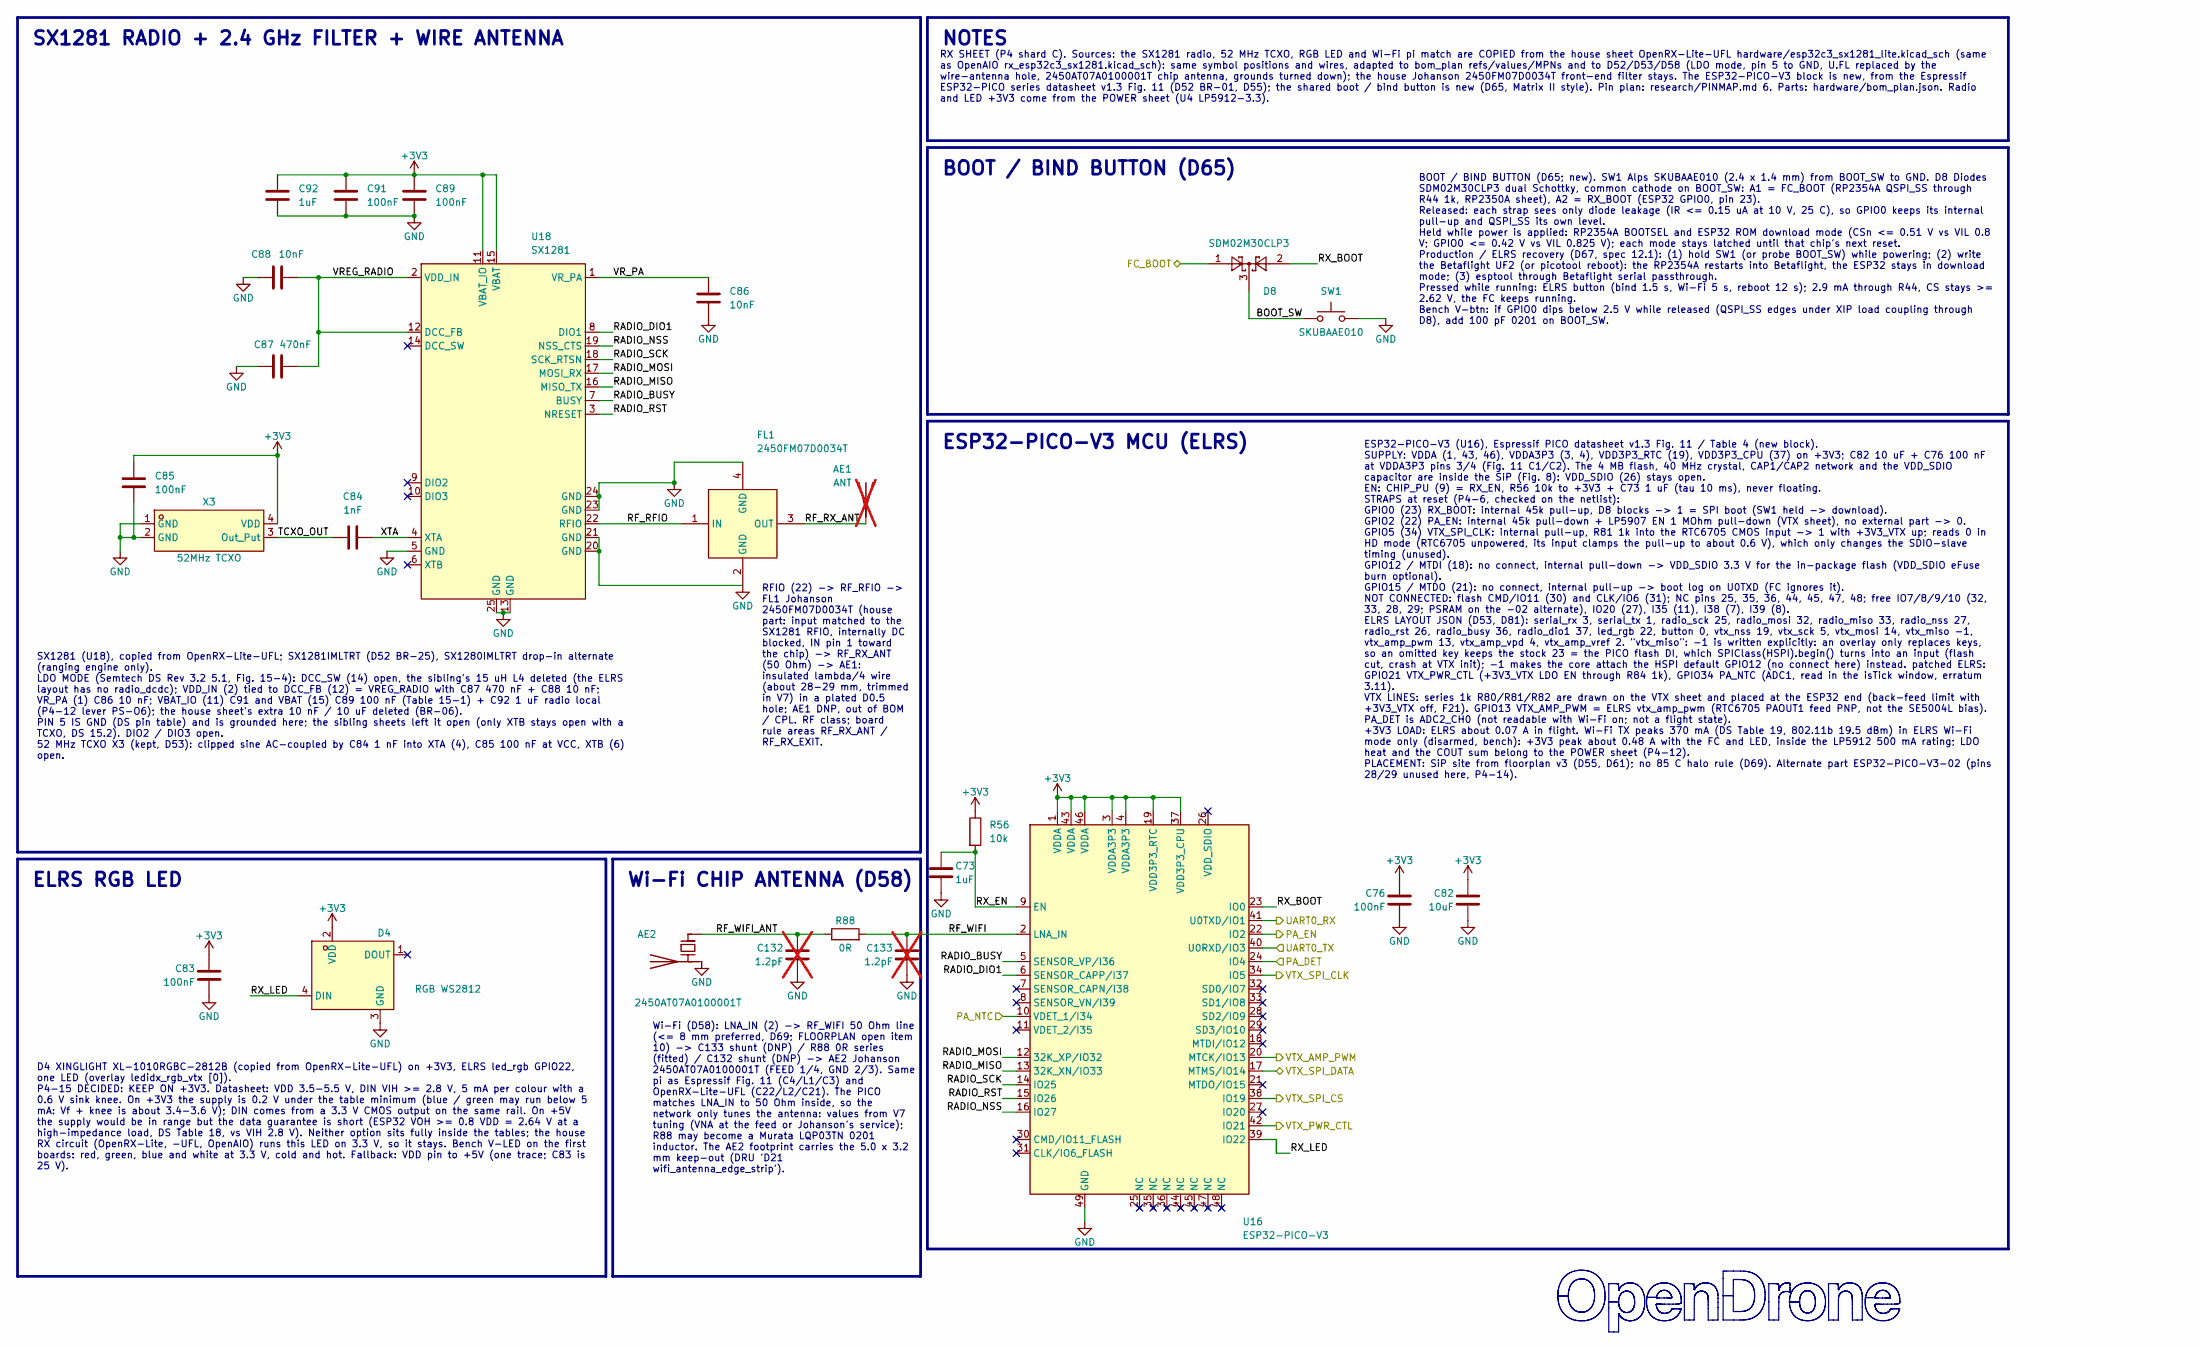
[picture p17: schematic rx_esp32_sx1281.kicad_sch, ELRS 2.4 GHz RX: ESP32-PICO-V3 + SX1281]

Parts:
AE1: ANT; AE_WireHole_PTH0.5mm; not fitted
AE2: 2450AT07A0100001T; ANT-SMD_4P-L1.0-W0.5_Johanson_2450AT07A0100_Edge5.0x3.2; MPN 2450AT07A0100001T
C73, C92: 1uF; C_0201_0603Metric_W; MPN GRM033R61A105ME44D; LCSC C76935
C76, C83, C85, C89, C91: 100nF; C_0201_0603Metric_W; MPN GRM033C81E104KE14D; LCSC C181047
C82: 10uF; C_0402_1005Metric_W; MPN GRM155C80J106ME11D; LCSC C237279
C84: 1nF; C_0201_0603Metric_W; MPN GRM033R71H102KA12D; LCSC C85934
C86, C88: 10nF; C_0201_0603Metric_W; MPN GRM033R71A103KA01D; LCSC C76941
C87: 470nF; C_0201_0603Metric_W; MPN GRM033R60J474KE90D; LCSC C85926
C132, C133: 1.2pF; C_0201_0603Metric_W; MPN GRM0335C1H1R2BA01D; LCSC C85895; not fitted
D4: RGB WS2812; LED-SMD_4P-L1.0-W1.0-TL_XL-1010RGBC-WS2812B_Dense; MPN XL-1010RGBC-2812B; LCSC C5349953
D8: SDM02M30CLP3; X2-DFN1006-3_L1.0-W0.6_SDM02M30CLP3; MPN SDM02M30CLP3-7B
FL1: 2450FM07D0034T; FILTER-SMD_4P-L1.0-W0.5-L_W; MPN 2450FM07D0034T; LCSC C2651081
R56: 10k; R_0201_0603Metric_W; MPN RC0201FR-0710KL; LCSC C106225
R88: 0R; R_0201_0603Metric_W; MPN RC0201JR-070RL
SW1: SKUBAAE010; SW_Alps_SKUBAAE010_2.4x1.4mm; MPN SKUBAAE010
U16: ESP32-PICO-V3; LGA-48_7x7mm_P0.5mm_EP_ESP32-PICO; MPN ESP32-PICO-V3; LCSC C967022
U18: SX1281; QFN-24_L4.0-W4.0-P0.50-TL-EP2.6_Dense; MPN SX1281IMLTRT; LCSC C2151551
X3: 52MHz TCXO; OSC-SMD_4P-L2.0-W1.6-BL_TXC_7Z_Dense; MPN OW7EL89CENUNFAYLC-52M; LCSC C22434896

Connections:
+3V3: C76.1, C82.1, C83.1, C85.1, C89.1, C91.1, C92.1, D4.2 (VDD), R56.1, U16.1 (VDDA), U16.3 (VDDA3P3), U16.4 (VDDA3P3), U16.19 (VDD3P3_RTC), U16.37 (VDD3P3_CPU), U16.43 (VDDA), U16.46 (VDDA), U18.11 (VBAT_IO), U18.15 (VBAT), X3.4 (VDD); also elsewhere on the board
/FC_BOOT: D8.1 (A1); also elsewhere on the board
/PA_DET: U16.24 (IO4); also elsewhere on the board
/PA_EN: U16.22 (IO2); also elsewhere on the board
/PA_NTC: U16.10 (VDET_1/I34); also elsewhere on the board
/RX/BOOT_SW: D8.3 (K), SW1.1
/RX/RADIO_BUSY: U16.5 (SENSOR_VP/I36), U18.7 (BUSY)
/RX/RADIO_DIO1: U16.6 (SENSOR_CAPP/I37), U18.8 (DIO1)
/RX/RADIO_MISO: U16.13 (32K_XN/IO33), U18.16 (MISO_TX)
/RX/RADIO_MOSI: U16.12 (32K_XP/IO32), U18.17 (MOSI_RX)
/RX/RADIO_NSS: U16.16 (IO27), U18.19 (NSS_CTS)
/RX/RADIO_RST: U16.15 (IO26), U18.3 (NRESET)
/RX/RADIO_SCK: U16.14 (IO25), U18.18 (SCK_RTSN)
/RX/RF_RFIO: FL1.1 (IN), U18.22 (RFIO)
/RX/RF_RX_ANT: AE1.1 (A_1), FL1.3 (OUT)
/RX/RF_WIFI: C133.1, R88.2, U16.2 (LNA_IN)
/RX/RF_WIFI_ANT: AE2.1 (FEED), AE2.4 (FEED), C132.1, R88.1
/RX/RX_BOOT: D8.2 (A2), U16.23 (IO0)
/RX/RX_EN: C73.1, R56.2, U16.9 (EN)
/RX/RX_LED: D4.4 (DIN), U16.39 (IO22)
/RX/TCXO_OUT: C84.1, X3.3 (Out_Put)
/RX/VREG_RADIO: C87.2, C88.2, U18.2 (VDD_IN), U18.12 (DCC_FB)
/RX/VR_PA: C86.1, U18.1 (VR_PA)
/RX/XTA: C84.2, U18.4 (XTA)
/UART0_RX: U16.41 (U0TXD/IO1); also elsewhere on the board
/UART0_TX: U16.40 (U0RXD/IO3); also elsewhere on the board
/VTX_AMP_PWM: U16.20 (MTCK/IO13); also elsewhere on the board
/VTX_PWR_CTL: U16.42 (IO21); also elsewhere on the board
/VTX_SPI_CLK: U16.34 (IO5); also elsewhere on the board
/VTX_SPI_CS: U16.38 (IO19); also elsewhere on the board
/VTX_SPI_DATA: U16.17 (MTMS/IO14); also elsewhere on the board
GND: AE2.2 (GND), AE2.3 (GND), C73.2, C76.2, C82.2, C83.2, C85.2, C86.2, C87.1, C88.1, C89.2, C91.2, C92.2, C132.2, C133.2, D4.3 (GND), FL1.2 (GND), FL1.4 (GND), SW1.2, U16.49 (GND), U18.5 (GND), U18.13 (GND), U18.20 (GND), U18.21 (GND), U18.23 (GND), U18.24 (GND), U18.25 (GND), X3.1 (GND), X3.2 (GND); also elsewhere on the board

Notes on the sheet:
NOTES
ELRS RGB LED
ESP32-PICO-V3 MCU (ELRS)
SX1281 RADIO + 2.4 GHz FILTER + WIRE ANTENNA
Wi-Fi CHIP ANTENNA (D58)
BOOT / BIND BUTTON (D65)
RFIO (22) -> RF_RFIO -> FL1 Johanson 2450FM07D0034T (house part: input matched to the SX1281 RFIO, internally DC blocked, IN pin 1 toward the chip) -> RF_RX_ANT (50 Ohm) -> AE1: insulated lambda/4 wire (about 28-29 mm, trimmed in V7) in a plated D0.5 hole; AE1 DNP, out of BOM / CPL. RF class; board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
BOOT / BIND BUTTON (D65; new). SW1 Alps SKUBAAE010 (2.4 x 1.4 mm) from BOOT_SW to GND. D8 Diodes SDM02M30CLP3 dual Schottky, common cathode on BOOT_SW: A1 = FC_BOOT (RP2354A QSPI_SS through R44 1k, RP2350A sheet), A2 = RX_BOOT (ESP32 GPIO0, pin 23). Released: each strap sees only diode leakage (IR 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
ESP32-PICO-V3 (U16), Espressif PICO datasheet v1.3 Fig. 11 / Table 4 (new block). SUPPLY: VDDA (1, 43, 46), VDDA3P3 (3, 4), VDD3P3_RTC (19), VDD3P3_CPU (37) on +3V3; C82 10 uF + C76 100 nF at VDDA3P3 pins 3/4 (Fig. 11 C1/C2). The 4 MB flash, 40 MHz crystal, CAP1/CAP2 network and the VDD_SDIO capaci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
SX1281 (U18), copied from OpenRX-Lite-UFL; SX1281IMLTRT (D52 BR-25), SX1280IMLTRT drop-in alternate (ranging engine only). LDO MODE (Semtech DS Rev 3.2 5.1, Fig. 15-4): DCC_SW (14) open, the sibling's 15 uH L4 deleted (the ELRS layout has no radio_dcdc); VDD_IN (2) tied to DCC_FB (12) = VREG_RADIO 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
Wi-Fi (D58): LNA_IN (2) -> RF_WIFI 50 Ohm line (<= 8 mm preferred, D69; FLOORPLAN open item 10) -> C133 shunt (DNP) / R88 0R series (fitted) / C132 shunt (DNP) -> AE2 Johanson 2450AT07A0100001T (FEED 1/4, GND 2/3). Same pi as Espressif Fig. 11 (C4/L1/C3) and OpenRX-Lite-UFL (C22/L2/C21). The PICO m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
D4 XINGLIGHT XL-1010RGBC-2812B (copied from OpenRX-Lite-UFL) on +3V3, ELRS led_rgb GPIO22, one LED (overlay ledidx_rgb_vtx [0]). P4-15 DECIDED: KEEP ON +3V3. Datasheet: VDD 3.5-5.5 V, DIN VIH >= 2.8 V, 5 mA per colour with a 0.6 V sink knee. On +3V3 the supply is 0.2 V under the table minimum (blue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
RX SHEET (P4 shard C). Sources: the SX1281 radio, 52 MHz TCXO, RGB LED and Wi-Fi pi match are COPIED from the house sheet OpenRX-Lite-UFL hardware/esp32c3_sx1281_lite.kicad_sch (same as OpenAIO rx_esp32c3_sx1281.kicad_sch): same symbol positions and wires, adapted to bom_plan refs/values/MPNs and t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

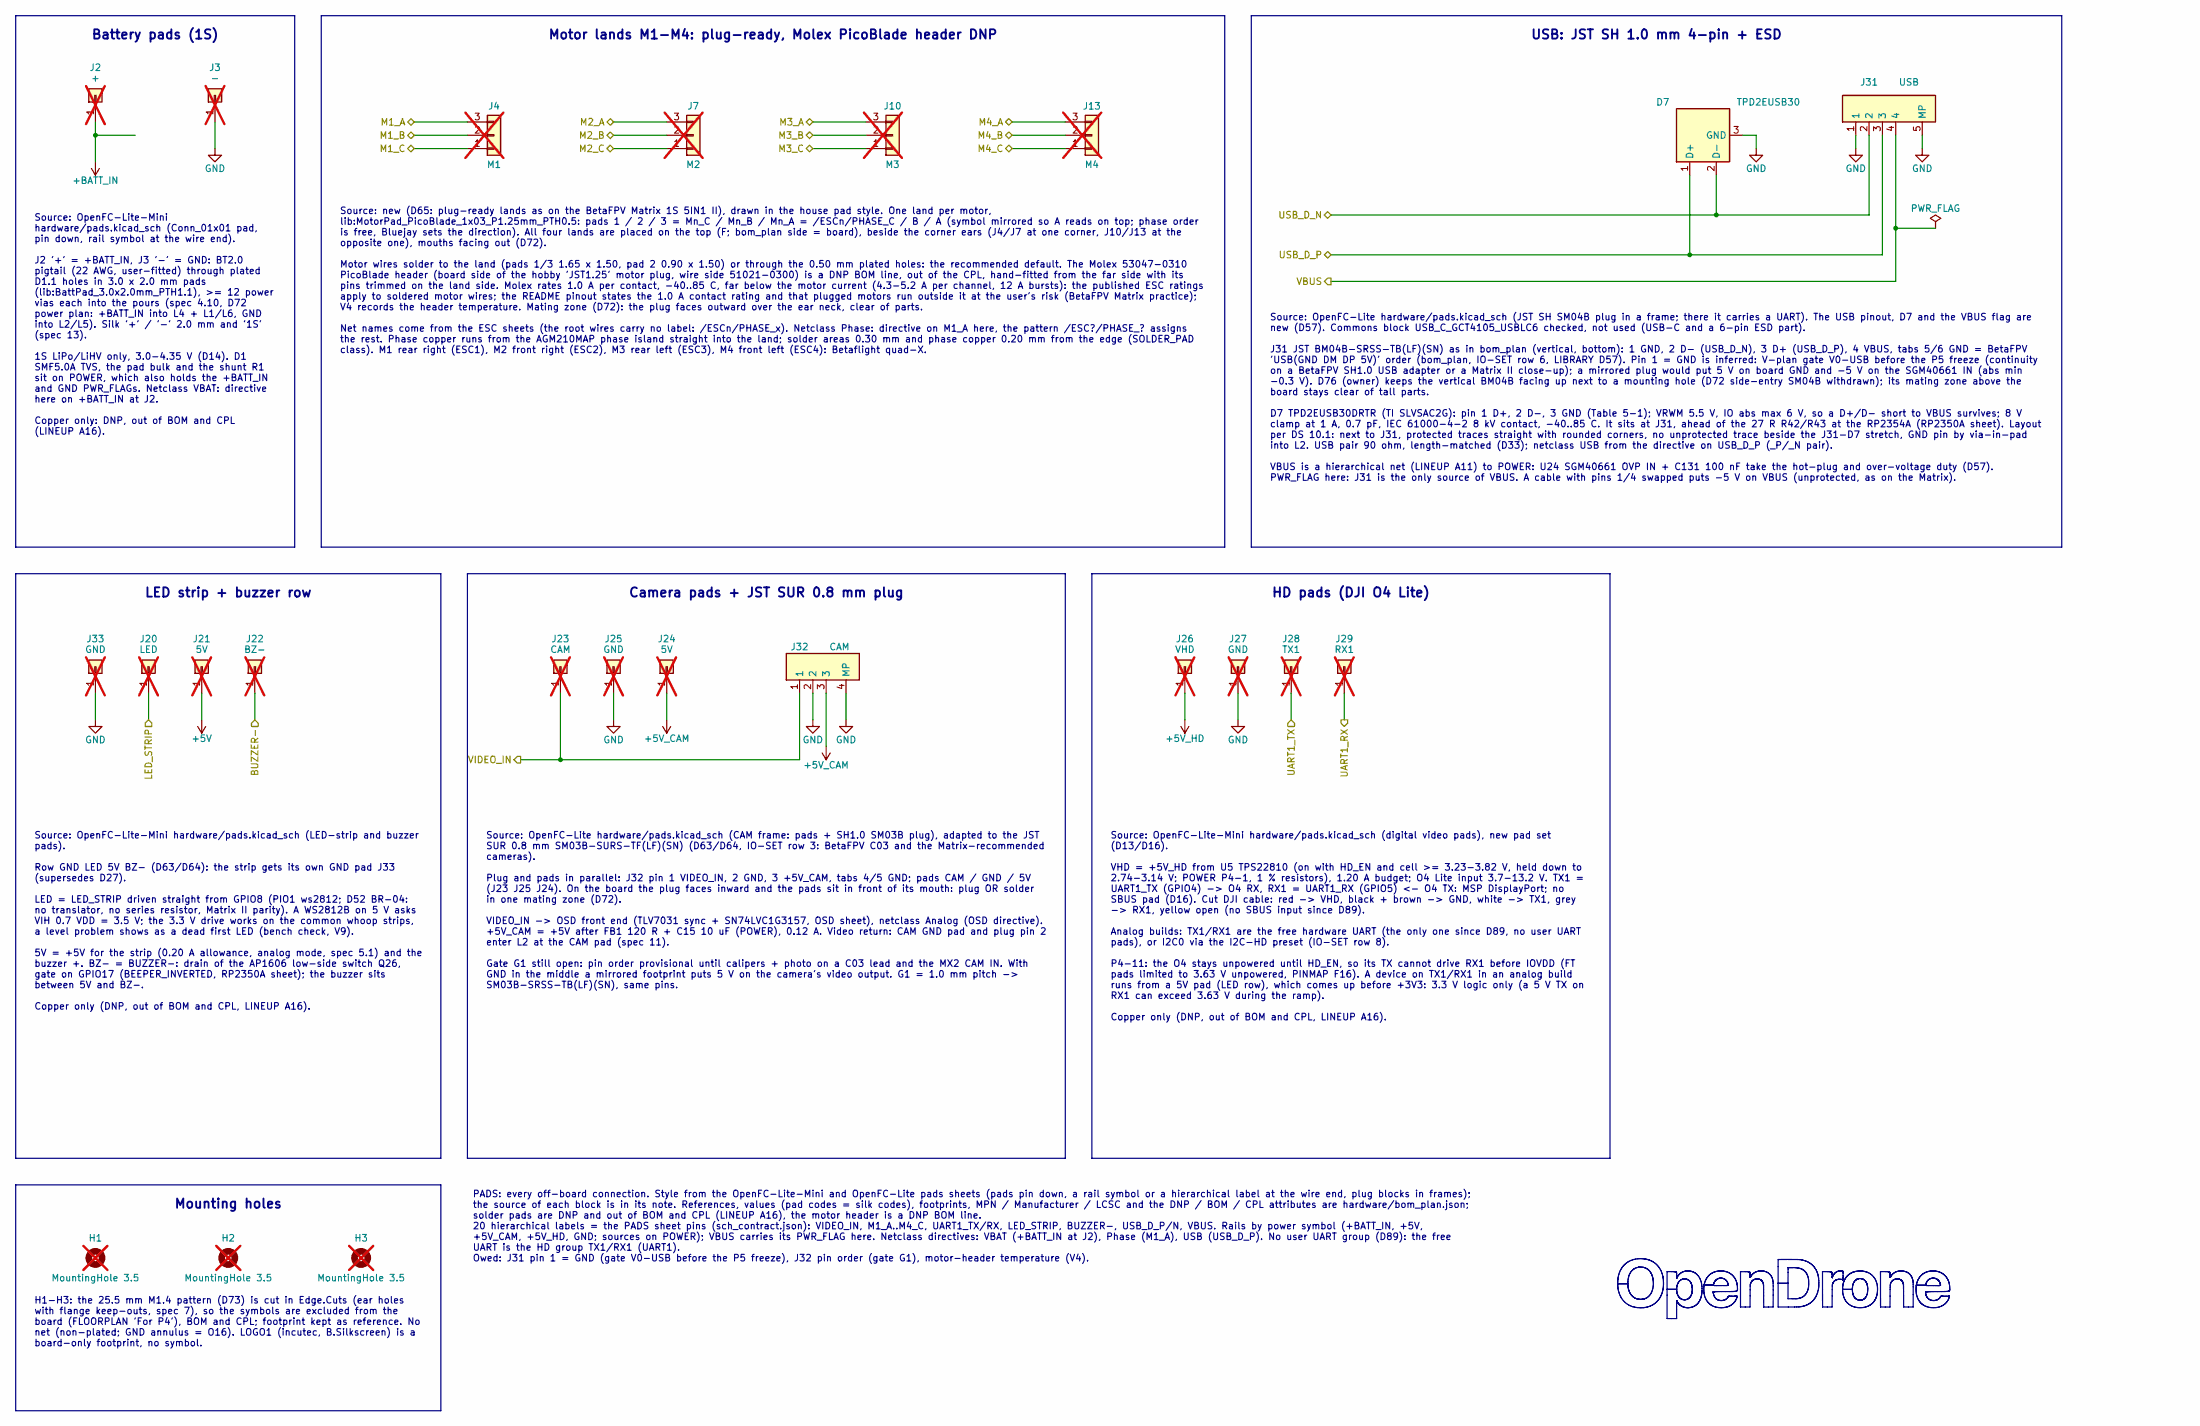
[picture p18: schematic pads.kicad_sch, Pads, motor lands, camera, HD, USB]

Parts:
D7: TPD2EUSB30; TI_SOT-9X3-3_DRT; MPN TPD2EUSB30DRTR; LCSC C97502
H1, H2, H3: MountingHole 3.5; MountingHole_3.5mm_Ear_Flange5.2; not fitted
J2: +; BattPad_3.0x2.0mm_PTH1.1; not fitted
J3: -; BattPad_3.0x2.0mm_PTH1.1; not fitted
J4: M1; MotorPad_PicoBlade_1x03_P1.25mm_PTH0.5; MPN 53047-0310; not fitted
J7: M2; MotorPad_PicoBlade_1x03_P1.25mm_PTH0.5; MPN 53047-0310; not fitted
J10: M3; MotorPad_PicoBlade_1x03_P1.25mm_PTH0.5; MPN 53047-0310; not fitted
J13: M4; MotorPad_PicoBlade_1x03_P1.25mm_PTH0.5; MPN 53047-0310; not fitted
J20: LED; SolderPad_1.0x1.2mm_Dense; not fitted
J21: 5V; SolderPad_1.0x1.2mm_Dense; not fitted
J22: BZ-; SolderPad_1.0x1.2mm_Dense; not fitted
J23: CAM; SolderPad_1.0x1.2mm; not fitted
J24: 5V; SolderPad_1.0x1.2mm; not fitted
J25, J27: GND; SolderPad_1.0x1.2mm; not fitted
J26: VHD; SolderPad_1.0x1.2mm; not fitted
J28: TX1; SolderPad_1.0x1.2mm; not fitted
J29: RX1; SolderPad_1.0x1.2mm; not fitted
J31: USB; CONN-SMD_4P-P1.00_BM04B-SRSS-TB; MPN BM04B-SRSS-TB(LF)(SN); LCSC C160390
J32: CAM; JST_SUR_SM03B-SURS-TF_1x03-1MP_P0.80mm_Horizontal; MPN SM03B-SURS-TF(LF)(SN); LCSC C265338
J33: GND; SolderPad_1.0x1.2mm_Dense; not fitted

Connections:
+5V: J21.1 (Pin_1_1); also elsewhere on the board
+5V_CAM: J24.1 (Pin_1_1), J32.3; also elsewhere on the board
+5V_HD: J26.1 (Pin_1_1); also elsewhere on the board
+BATT_IN: J2.1 (Pin_1_1); also elsewhere on the board
/BUZZER-: J22.1 (Pin_1_1); also elsewhere on the board
/ESC1/PHASE_A: J4.3; also elsewhere on the board
/ESC1/PHASE_B: J4.2; also elsewhere on the board
/ESC1/PHASE_C: J4.1; also elsewhere on the board
/ESC2/PHASE_A: J7.3; also elsewhere on the board
/ESC2/PHASE_B: J7.2; also elsewhere on the board
/ESC2/PHASE_C: J7.1; also elsewhere on the board
/ESC3/PHASE_A: J10.3; also elsewhere on the board
/ESC3/PHASE_B: J10.2; also elsewhere on the board
/ESC3/PHASE_C: J10.1; also elsewhere on the board
/ESC4/PHASE_A: J13.3; also elsewhere on the board
/ESC4/PHASE_B: J13.2; also elsewhere on the board
/ESC4/PHASE_C: J13.1; also elsewhere on the board
/LED_STRIP: J20.1 (Pin_1_1); also elsewhere on the board
/UART1_RX: J29.1 (Pin_1_1); also elsewhere on the board
/UART1_TX: J28.1 (Pin_1_1); also elsewhere on the board
/USB_D_N: D7.2 (D-), J31.2; also elsewhere on the board
/USB_D_P: D7.1 (D+), J31.3; also elsewhere on the board
/VBUS: J31.4; also elsewhere on the board
/VIDEO_IN: J23.1 (Pin_1_1), J32.1; also elsewhere on the board
GND: D7.3 (GND), J3.1 (Pin_1_1), J25.1 (Pin_1_1), J27.1 (Pin_1_1), J31.1, J31.5 (MP), J31.6 (MP), J32.2, J32.4 (MP), J32.5 (MP), J33.1 (Pin_1_1); also elsewhere on the board

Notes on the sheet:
Mounting holes
Motor lands M1-M4: plug-ready, Molex PicoBlade header DNP
Battery pads (1S)
USB: JST SH 1.0 mm 4-pin + ESD
LED strip + buzzer row
Camera pads + JST SUR 0.8 mm plug
HD pads (DJI O4 Lite)
Source: OpenFC-Lite hardware/pads.kicad_sch (CAM frame: pads + SH1.0 SM03B plug), adapted to the JST SUR 0.8 mm SM03B-SURS-TF(LF)(SN) (D63/D64, IO-SET row 3: BetaFPV C03 and the Matrix-recommended cameras). Plug and pads in parallel: J32 pin 1 VIDEO_IN, 2 GND, 3 +5V_CAM, tabs 4/5 GND; pads CAM / GN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
H1-H3: the 25.5 mm M1.4 pattern (D73) is cut in Edge.Cuts (ear holes with flange keep-outs, spec 7), so the symbols are excluded from the board (FLOORPLAN 'For P4'), BOM and CPL; footprint kept as reference. No net (non-plated; GND annulus = O16). LOGO1 (incutec, B.Silkscreen) is a board-only footp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
Source: OpenFC-Lite hardware/pads.kicad_sch (JST SH SM04B plug in a frame; there it carries a UART). The USB pinout, D7 and the VBUS flag are new (D57). Commons block USB_C_GCT4105_USBLC6 checked, not used (USB-C and a 6-pin ESD part). J31 JST BM04B-SRSS-TB(LF)(SN) as in bom_plan (vertical, bottom)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
Source: OpenFC-Lite-Mini hardware/pads.kicad_sch (digital video pads), new pad set (D13/D16). VHD = +5V_HD from U5 TPS22810 (on with HD_EN and cell >= 3.23-3.82 V, held down to 2.74-3.14 V; POWER P4-1, 1 % resistors), 1.20 A budget; O4 Lite input 3.7-13.2 V. TX1 = UART1_TX (GPIO4) -> O4 RX, RX1 = U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
Source: OpenFC-Lite-Mini hardware/pads.kicad_sch (LED-strip and buzzer pads). Row GND LED 5V BZ- (D63/D64): the strip gets its own GND pad J33 (supersedes D27). LED = LED_STRIP driven straight from GPIO8 (PIO1 ws2812; D52 BR-04: no translator, no series resistor, Matrix II parity). A WS2812B on 5 V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
Source: OpenFC-Lite-Mini hardware/pads.kicad_sch (Conn_01x01 pad, pin down, rail symbol at the wire end). J2 '+' = +BATT_IN, J3 '-' = GND: BT2.0 pigtail (22 AWG, user-fitted) through plated D1.1 holes in 3.0 x 2.0 mm pads (lib:BattPad_3.0x2.0mm_PTH1.1), >= 12 power vias each into the pours (spec 4.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
Source: new (D65: plug-ready lands as on the BetaFPV Matrix 1S 5IN1 II), drawn in the house pad style. One land per motor, lib:MotorPad_PicoBlade_1x03_P1.25mm_PTH0.5: pads 1 / 2 / 3 = Mn_C / Mn_B / Mn_A = /ESCn/PHASE_C / B / A (symbol mirrored so A reads on top; phase order is free, Bluejay sets th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
PADS: every off-board connection. Style from the OpenFC-Lite-Mini and OpenFC-Lite pads sheets (pads pin down, a rail symbol or a hierarchical label at the wire end, plug blocks in frames); the source of each block is in its note. References, values (pad codes = silk codes), footprints, MPN / Manufa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

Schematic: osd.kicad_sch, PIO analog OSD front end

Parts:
C66: 100pF; C_0201_0603Metric_W; MPN GRM0335C1H101JA01D
C67: 470pF; C_0201_0603Metric_W; MPN CC0201JRX7R9BB471; LCSC C526944
C68: 1uF; C_0201_0603Metric_W; MPN GRM033R61A105ME44D; LCSC C76935
C70: 100nF; C_0201_0603Metric_W; MPN GRM033C81E104KE14D; LCSC C181047
D3: SDM02U30LP3; X3-DFN0603-2_L0.6-W0.3-RD_W; MPN SDM02U30LP3-7B; LCSC C151629
R51: 75R; R_0201_0603Metric_W; MPN RC0201FR-0775RL; LCSC C274878
R52: 820R; R_0201_0603Metric_W; MPN RC0201FR-07820RL
R53: 2.4k; R_0201_0603Metric_W; MPN RTT012401FTH; LCSC C166281
R54: 270R; R_0201_0603Metric_W; MPN RC0201FR-07270RL
R55: 680R; R_0201_0603Metric_W; MPN RC0201FR-07680RL; LCSC C274876
U14: SN74LVC1G3157; X2SON-6_L1.0-W0.8-BL_Dense; MPN SN74LVC1G3157DTBR; LCSC C2673087
U15: TLV7031; X2SON-4_L0.8-W0.8-P0.48-TL-A_Dense; MPN TLV7031DPWR; LCSC C2876045

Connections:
+3V3: C70.1, R53.2, U14.5 (VCC), U15.2 (V+); also elsewhere on the board
/OSD/OSD_LVL: R52.2, R53.1, R54.2, U14.1 (B2)
/OSD/VID_DC: C68.2, D3.1 (C), U15.5 (IN+)
/OSD/VID_FILT: C67.1, C68.1, R55.1
/OSD_EN: U14.6 (S); also elsewhere on the board
/OSD_SYNC: U15.1 (OUT); also elsewhere on the board
/OSD_W: R52.1; also elsewhere on the board
/VIDEO_IN: C66.1, R51.1, R55.2, U14.3 (B1); also elsewhere on the board
/VIDEO_OUT: U14.4 (A); also elsewhere on the board
GND: C66.2, C67.2, C70.2, D3.2 (A), R51.2, R54.1, U14.2 (GND), U15.3 (V-), U15.4 (IN-); also elsewhere on the board

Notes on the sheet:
OSD_EN
Resistor divider lets the OSD_W GPIO select white (high: 1.05 V) or black (low: 0.27 V)
Analog switch
OSD_W
VIDEO PATH
black pixel
U15 V+ (2) is decoupled by C70 in the switch cell, one 100n shared with U14 (BR-13)
Sync detection, VID_DC sync tips clamped to -VF (about -0.1..-0.2 V)
transparent
Chroma Filter fc = 500 kHz
S low (OSD_EN low / reset): B1 camera S high: B2 OSD level
75R input termination 100p entry shunt
white pixel
DC Restoration
Comparator: OSD_SYNC low during sync, read by RP2354A PIO2 (GPIO16)
Placement (P5; P4-17 sheet note): bottom, region osd. BR-13: C70 is the only supply cap of U14 (VCC 5) and U15 (V+ 2): place it between the two parts (2.5 mm apart), GND via-in-pad; the P5 check lists its distance to both pins. U15 centre pad (3, V-) to GND through a via (TI 7.4). R51 and C66 at th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
Source: OpenFC-Lite-Mini hardware/osd.kicad_sch (rev2, flown), copied and adapted: cells, texts, truth table and part spots kept (A3 -> A4). Same topology: 75R termination, 680R/470p chroma filter, 1u + SDM02U30LP3 sync-tip clamp, TLV7031 comparator, SN74LVC1G3157 camera/level switch (contract sour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
VIDEO_OUT: the switch output drives the RTC6705 video network on the VTX sheet directly (R58 1.2k || C104 33p, R59 270R, C105 4.7u, R60 1.2k: OpenOSD-X values); the house COS8051 buffer (U1, R46-R48, C41) is deleted (spec 4.8). OSD levels (P4-10, recomputed at the P4 critique with the real load): o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

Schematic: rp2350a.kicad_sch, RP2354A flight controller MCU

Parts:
C42, C43: 15pF; C_0201_0603Metric_W; MPN GRM0335C1H150JA01D; LCSC C85891
C44, C45, C46, C47, C48, C49, C50, C51, C52, C54, C59, C60: 100nF; C_0201_0603Metric_W; MPN GRM033C81E104KE14D; LCSC C181047
C56, C57, C58, C134: 4.7uF; C_0402_1005Metric_W; MPN CL05A475MP5NRNC; LCSC C23733
L2: 3.3uH; IND-SMD_L2.0-W1.6_AOTA-B201610S3R3-101-T_Dense; MPN AOTA-B201610S3R3-101-T; LCSC C42411119
Q26: AP1606; DFN-3L_L1.0-W0.6-P0.65-BR_W; MPN AP1606; LCSC C2849580
R40, R44, R47: 1k; R_0201_0603Metric_W; MPN RC0201FR-071KL
R41, R42, R43: 27R; R_0201_0603Metric_W; MPN RC0201FR-0727RL
R45, R46: 10k; R_0201_0603Metric_W; MPN RC0201FR-0710KL; LCSC C106225
R48: 100k; R_0201_0603Metric_W; MPN RC0201FR-07100KL; LCSC C106224
TP9: FCB; TestPoint_Via_D0.35mm_Drill0.2mm
TP12: CLK; TestPoint_Via_D0.35mm_Drill0.2mm
TP13: DIO; TestPoint_Via_D0.35mm_Drill0.2mm
U10: RP2354A; QFN-60_L7.0-W7.0-P0.40-TL-EP3.4_Dense; MPN RP2354A; LCSC C41378174
X1: 12MHz; CRYSTAL-SMD_4P-L3.2-W2.5-BL_Dense; MPN ABM8-272-T3; LCSC C20625731

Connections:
+1V1: C50.1, C51.1, C52.1, C56.1, C134.1, L2.1, U10.6 (DVDD), U10.23 (DVDD), U10.39 (DVDD), U10.50 (VREG_FB)
+3V3: C44.1, C45.1, C46.1, C47.1, C48.1, C49.1, C54.1, C58.1, R41.1, U10.1 (IOVDD), U10.11 (IOVDD), U10.20 (IOVDD), U10.26 (RUN), U10.30 (IOVDD), U10.38 (IOVDD), U10.44 (ADC_AVDD), U10.45 (IOVDD), U10.49 (VREG_VIN), U10.53 (USB_OTP_VDD), U10.54 (QSPI_IOVDD); also elsewhere on the board
+BATT: R45.2; also elsewhere on the board
/BUZZER-: Q26.3 (D); also elsewhere on the board
/CURR_SENSE: R47.1; also elsewhere on the board
/FC_BOOT: R44.2, TP9.1 (1_1); also elsewhere on the board
/FLASH_CS: U10.33 (GPIO21); also elsewhere on the board
/GYRO_CLKIN: U10.9 (GPIO6); also elsewhere on the board
/GYRO_CS: U10.17 (GPIO13); also elsewhere on the board
/GYRO_INT: U10.13 (GPIO9); also elsewhere on the board
/HD_EN: U10.41 (GPIO27_ADC1); also elsewhere on the board
/LED0: U10.10 (GPIO7); also elsewhere on the board
/LED1: U10.40 (GPIO26_ADC0); also elsewhere on the board
/LED_STRIP: U10.12 (GPIO8); also elsewhere on the board
/MOTOR1: U10.37 (GPIO25); also elsewhere on the board
/MOTOR2: U10.36 (GPIO24); also elsewhere on the board
/MOTOR3: U10.35 (GPIO23); also elsewhere on the board
/MOTOR4: U10.34 (GPIO22); also elsewhere on the board
/OSD_EN: U10.19 (GPIO15); also elsewhere on the board
/OSD_SYNC: U10.27 (GPIO16); also elsewhere on the board
/OSD_W: U10.18 (GPIO14); also elsewhere on the board
/PIOUART0_RX: U10.5 (GPIO3); also elsewhere on the board
/PIOUART0_TX: U10.4 (GPIO2); also elsewhere on the board
/RP2350A/ADC_CURR: C60.1, R47.2, U10.42 (GPIO28_ADC2)
/RP2350A/ADC_VBAT: C59.2, R45.1, R46.2, U10.43 (GPIO29_ADC3)
/RP2350A/BEEPER: Q26.1 (G), R48.2, U10.28 (GPIO17)
/RP2350A/QSPI_SS: R44.1, U10.60 (QSPI_SS)
/RP2350A/SWCLK: TP12.1 (1_1), U10.24 (SWCLK)
/RP2350A/SWDIO: TP13.1 (1_1), U10.25 (SWDIO)
/RP2350A/U10_USB_DM: R43.2, U10.51 (USB_DM)
/RP2350A/U10_USB_DP: R42.1, U10.52 (USB_DP)
/RP2350A/VREG_AVDD: C57.1, R41.2, U10.46 (VREG_AVDD)
/RP2350A/VREG_LX: L2.2, U10.48 (VREG_LX)
/RP2350A/XIN: C42.1, U10.21 (XIN), X1.1
/RP2350A/XOUT: R40.2, U10.22 (XOUT)
/RP2350A/XOUT_X: C43.1, R40.1, X1.3
/SPI0_MISO: U10.32 (GPIO20); also elsewhere on the board
/SPI0_MOSI: U10.31 (GPIO19); also elsewhere on the board
/SPI0_SCK: U10.29 (GPIO18); also elsewhere on the board
/SPI1_MISO: U10.16 (GPIO12); also elsewhere on the board
/SPI1_MOSI: U10.15 (GPIO11); also elsewhere on the board
/SPI1_SCK: U10.14 (GPIO10); also elsewhere on the board
/UART0_RX: U10.3 (GPIO1); also elsewhere on the board
/UART0_TX: U10.2 (GPIO0); also elsewhere on the board
/UART1_RX: U10.8 (GPIO5); also elsewhere on the board
/UART1_TX: U10.7 (GPIO4); also elsewhere on the board
/USB_D_N: R43.1; also elsewhere on the board
/USB_D_P: R42.2; also elsewhere on the board
GND: C42.2, C43.2, C44.2, C45.2, C46.2, C47.2, C48.2, C49.2, C50.2, C51.2, C52.2, C54.2, C56.2, C57.2, C58.2, C59.1, C60.2, C134.2, Q26.2 (S), R46.1, R48.1, U10.47 (VREG_PGND), U10.61 (EP), X1.2 (G), X1.4 (G); also elsewhere on the board

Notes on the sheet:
gyro SPI1 (IMU; GYRO_CS pull-up R49 there)
current sense RC, 1.6 kHz
decoupling caps, place close to IC, one is enough when 2 pins are next to each other
for MSP DisplayPort: DJI O4 Lite TX1/RX1
for CRSF receiver (ESP32 ELRS, UART0)
Boot strap + SWD test vias
blackbox SPI0 (FLASH_CS pull-up R50 there)
HD line PINIO1: high = O4 on, analog VTX off
PIO2 framebuffer OSD: W, EN, SYNC consecutive
in-package flash on QSPI: SD0-SD3, SCLK no-connect
status LEDs (LED sheet, sinking)
vbat sense, 1/2 scale
GPIO2/3 spare, no-connect (D89)
buzzer with N-MOS low side switch
WS2812 pad LED, driven direct (F1, BR-04)
gyro CLKIN (ICM-42688-P only)
RP2354A: Smaller variant with integrated flash (2MB)
Crystal per datasheet. 10pF loading = 2x 15pF in series + ~2.5pF stray
PIO0 bidir. DShot to the EFM8s (2.4k at the EFM8)
R44 1k from QSPI_SS (pin 60, BOOT) to FC_BOOT: the shared boot button SW1 pulls FC_BOOT low through D8 (RX sheet, D65); low at reset = BOOTSEL / UF2. 1k (RPi hardware guide R6); CSn <= 0.51 V with the diode drop (VIL 0.8 V). Keep the QSPI_SS-to-R44 stub <= 1 mm (in-package flash CS, RPi guide R6); 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
DVDD 6/23/39: C50-C52. IOVDD 1/11/20/30/38: C44-C48, one per pin. C49 sits at ADC_AVDD pin 44 and also serves IOVDD 45 (BR-08; RP2350 DS 6.1.5: 100 nF close to ADC_AVDD). C54 <= 1 mm from QSPI_IOVDD pin 54 (the in-package flash supply, 2.97-3.63 V) and also serves USB_OTP_VDD 53 (BR-08, P4-17 place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
SHEET RP2350A, source: OpenFC-Lite-Mini/hardware/rp2350a.kicad_sch (flown Rev2), copied block by block with its layout, frames and text style. Changes: USB-C + CC removed (USB = JST SH J31 + D7 on PADS; 27R series R42/R43 stay at U10, D52 BR-21 value); I2C0 pull-ups removed (GPIO4/5 = UART1); the i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
X1 Abracon ABM8-272-T3 = the crystal RP2350 DS 8.2.1.1 Table 629 names (12 MHz, CL 10 pF, ESR <= 50 Ohm, -40..85 C); C42/C43 15 pF and the XOUT 1k R40 are the RPi guide values for it (OpenFC R5). D78: replaces the 150 Ohm 2520 part. X1, C42, C43, R40 at pins 21/22, nothing switching under them.
R42/R43 27R within 1-2 mm of pins 52/51 (RPi HW design 5.1, house 30R). USB_D_P/N: 90 ohm pair over unbroken GND, length-matched (D33); D7 ESD + J31 on PADS. Pin-side nets U10_USB_DP/DM.
Q26 AP1606 (copied from OpenFC-Lite-Mini rp2350a, Q5 there): 20 V, 0.7 A, Vgs(th) 0.4-1.2 V, RDS(on) <= 220 mOhm at Vgs 2.5 V (ALLPOWER DS p2). GPIO17 high = on (BEEPER_INVERTED, active buzzer, no PWM); R48 100k holds the gate low through reset. BZ+ = +5V and BZ- = drain on the GND LED 5V BZ- pad r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
RP2350 1.1V DC-DC SMPS: follow the datasheet placement. RP2350 DS 6.3.8 (binding): C58 = CIN at VREG_VIN, C56 = COUT on +1V1 with VREG_FB taken from the C56 pad (not under L2); C58, L2 and C56 on the U10 side, smallest hot loops; CIN/COUT GND to VREG_PGND at one point with 2 vias; no copper under L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
P4-11 power-up and 5 V-tolerant pads (PINMAP 4.5, F16; RP2350 DS Table 1433): an FT pad takes <= 3.63 V while IOVDD is 0-1.8 V (4.2 V at 2.5 V, 5.5 V at 3.3 V); the ADC pads GPIO26-29 take <= IOVDD + 0.5 V. - MOTOR1-4 (GPIO25-22, FT), battery first: each EFM8 weak pull-up (70-220 kOhm to VDD = cell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
VBAT: R45/R46 10k/10k (house 100k/10k), 4.35 V -> 2.18 V on GPIO29 (ADC3, not 5 V tolerant), vbat_scale 200/100; 5 kOhm with C59 = 318 Hz. CURR: R47 1k + C60 100 nF = 1.6 kHz on GPIO28 (ADC2); INA186A3 on POWER, 50 mV/A, ibata_scale 500. Copied from OpenFC-Lite-Mini rp2350a (vbat + ESC current).

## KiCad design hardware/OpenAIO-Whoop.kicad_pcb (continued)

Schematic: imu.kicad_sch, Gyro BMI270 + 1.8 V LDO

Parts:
C61, C62: 1uF; C_0201_0603Metric_W; MPN GRM033R61A105ME44D; LCSC C76935
R49: 10k; R_0201_0603Metric_W; MPN RC0201FR-0710KL; LCSC C106225
U11: BMI270; LGA-14_L3.0-W2.5-P0.50-BR_W; MPN BMI270; LCSC C2836813
U12: TPS7A2018; X2SON-4_L1.0-W1.0-P0.65-TL-EP_Dense; MPN TPS7A2018PDQNRM3; LCSC C36996449

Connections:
+1V8: C62.1, U11.8 (VDD), U12.1 (OUT)
+3V3: C61.1, R49.2, U11.5 (VDDIO), U12.3 (EN), U12.4 (IN); also elsewhere on the board
/GYRO_CLKIN: U11.9 (INT2); also elsewhere on the board
/GYRO_CS: R49.1, U11.12 (CSB); also elsewhere on the board
/GYRO_INT: U11.4 (INT1); also elsewhere on the board
/SPI1_MISO: U11.1 (SDO); also elsewhere on the board
/SPI1_MOSI: U11.14 (SDx); also elsewhere on the board
/SPI1_SCK: U11.13 (SCx); also elsewhere on the board
GND: C61.2, C62.2, U11.6 (GNDIO), U11.7 (GND), U12.2 (GND), U12.5 (EP); also elsewhere on the board

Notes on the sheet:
Universal IMU wiring and LGA-14 land (BMI270, ICM-42688-P)
GYRO BMI270: U11, R49 Source: OpenFC-Lite-Mini imu.kicad_sch (universal LGA-14 land, SPI1 4-wire, R49), copied and adapted. BMI270 on the BOM; TDK ICM-42688-P qualified on the same land (V10 fly-off, one part per revision). Pins 2/3 (BMI270 ASDx/ASCx, TDK RESV) and 10/11 (OCSB/OSDO, TDK RESV): no-c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
+1V8 GYRO LDO: U12, C61, C62 (D52 BR-09, P4-17) Source: pcb-agent-commons blocks/LDO_IMU_TPS7A2033 (OpenFC-H7) topology with the 1.8 V part and no ferrite (fed from the +3V3 LDO); the house OpenFC-Lite-Mini also runs the gyro VDD from its own 1.8 V LDO. TPS7A2018 DQN: 1 OUT, 2 GND, 3 EN, 4 IN, 5 EP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

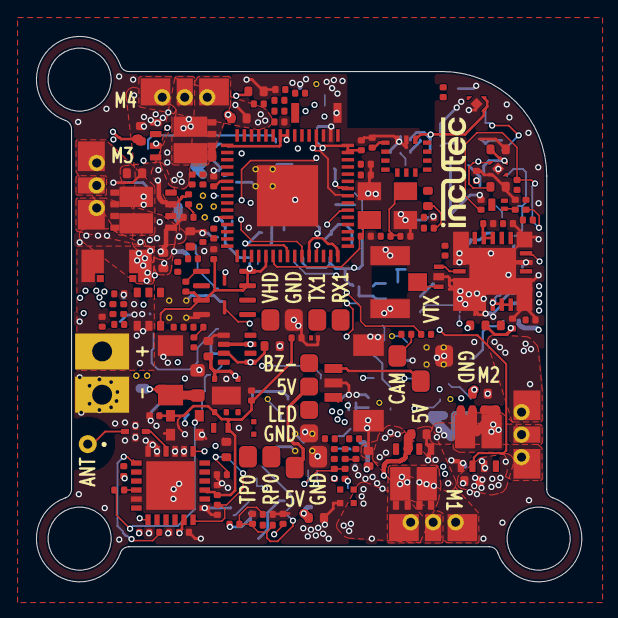
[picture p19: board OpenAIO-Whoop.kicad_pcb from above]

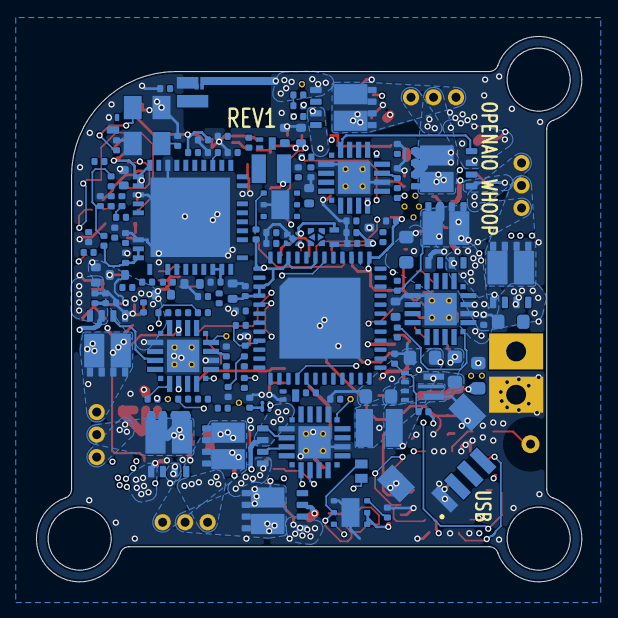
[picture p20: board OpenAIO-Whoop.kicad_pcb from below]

Board: 6 copper layers, 30.3 x 30.3 mm, 272 parts (125 on the bottom side), 190 nets.

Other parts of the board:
J16: TP0; SolderPad_1.0x1.2mm
J17: RP0; SolderPad_1.0x1.2mm
J18: 5V; SolderPad_1.0x1.2mm
J19: GND; SolderPad_1.0x1.2mm
LOGO1: incutec; incutec_logo_6.1x1.4mm

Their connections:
+5V: J18.1 (Pin_1_1); also elsewhere on the board
/PIOUART0_RX: J17.1 (Pin_1_1); also elsewhere on the board
/PIOUART0_TX: J16.1 (Pin_1_1); also elsewhere on the board
GND: J19.1 (Pin_1_1); also elsewhere on the board

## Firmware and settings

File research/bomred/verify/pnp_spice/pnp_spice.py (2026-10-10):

#!/usr/bin/env python3
"""P4-5 SPICE gate for the VTX PA drive stage (D52 BR-02), ngspice 42 + Nexperia BC857BM model (week 19/2020).

Stage: PA_BIAS_PWM (ESP32 GPIO13, 10 kHz, ELRS count/4096) -> R71 1k -> C124 1u -> R72 1k -> C125 1u -> Q27 base;
Q27 emitter -> R73 Re -> +3V3_VTX; collector -> R65 10R -> PAOUT1_SUP (C109 10n) -> L3 4.7n -> PAOUT1.
PAOUT1 load model: internal RTC6705 output stage = current sink with a 0.25 V knee, I = Imax*tanh(V/0.25)
(the datasheet gives the PAOUT1 current as TBD; Imax swept, 95 mA = whole-chip upper bound).
hFE spread: BF scaled so hFE(-5 V, -2 mA, 25 C) = 220 / typ / 475 (datasheet group B limits).
"""
import os, re, subprocess, sys, math, tempfile

HERE = os.path.dirname(os.path.abspath(__file__))
MODEL = open(os.path.join(HERE, "dl", "BC857BM.txt")).read()
VDD = 3.3


def model_bf(scale):
    """BC857BM subckt with BF scaled; subckt renamed per scale."""
    m = MODEL.replace(".SUBCKT BC857BM", ".SUBCKT BC857BM_%d" % int(scale * 1000))
    m = re.sub(r"\+ BF = ([0-9.Ee+-]+)", lambda g: "+ BF = %g" % (float(g.group(1)) * scale), m)
    m = m.replace(".MODEL MAIN PNP", ".MODEL MAIN%d PNP" % int(scale * 1000))
    m = re.sub(r"(Q[12] \S+ \S+ \S+) MAIN ", lambda g: g.group(1) + " MAIN%d " % int(scale * 1000), m)
    m = m.replace(".MODEL DIODE D", ".MODEL DIODE%d D" % int(scale * 1000)).replace("D1 1 2 DIODE",
                                                                                    "D1 1 2 DIODE%d" % int(scale * 1000))
    return m, "BC857BM_%d" % int(scale * 1000)


def run(net):
    with tempfile.NamedTemporaryFile("w", suffix=".cir", delete=False, dir=HERE) as f:
        f.write(net)
        p = f.name
    r = subprocess.run(["ngspice", "-b", p], capture_output=True, text=True, timeout=300)
    os.unlink(p)
    return r.stdout + r.stderr


def hfe(scale, temp=25):
    m, name = model_bf(scale)
    fn = os.path.join(HERE, "_hfe.dat")
    run("""* hfe
%s
.temp %g
VC c 0 -5
IB b 0 1u
XQ c b 0 %s
.control
dc IB 0.5u 40u 0.05u
wrdata %s -i(VC)
.endc
.end
""" % (m, temp, name, fn))
    rows = [tuple(float(x) for x in l.split()) for l in open(fn) if l.strip()]
    os.unlink(fn)
    # columns: ib, -i(VC) (collector current flowing out of the collector into VC is +i(VC) -> sign either way)
    best = min(rows, key=lambda r: abs(abs(r[1]) - 2e-3))
    return abs(best[1]) / best[0]


STAGE = """
VDD vdd 0 {vdd}
RE vdd e {re}
XQ c b e {q}
R65 c sup 10
C109 sup 0 10n
L3 sup pa 4.7n
BLOAD pa 0 I = {imax}*tanh(v(pa)/0.25)
RLEAK pa 0 100k
R71 pwm n1 1k
C124 n1 0 {cfx}
R72 n1 b 1k
C125 b 0 {cfx}
"""


def dc_sweep(re_, scale, temp, imax, counts):
    """Averaged-PWM DC: Vpwm = 3.3*duty, duty = int(count*1000/4096)/1000 (ELRS setDuty)."""
    m, name = model_bf(scale)
    lines = ["* dc", m, ".temp %g" % temp,
             STAGE.format(vdd=VDD, re=re_, q=name, imax=imax, cfx="1u"),
             "VPWM pwm 0 0", ".control"]
    for c in counts:
        d = (c * 1000 // 4096) / 1000.0
        lines += ["alter VPWM %g" % (VDD * d), "op", "echo @@%d" % c,
                  "print -i(VDD) v(pa) v(e)-v(c) v(e)-v(b)"]
    lines += [".endc", ".end"]
    out = run("\n".join(lines))
    res = {}
    for blk in out.split("@@")[1:]:
        c = int(blk.split()[0])
        try:
            g = lambda k: float(re.search(k + r" = ([-0-9.eE+]+)", blk).group(1))
            res[c] = (g(r"-i\(vdd\)"), g(r"v\(pa\)"), g(r"v\(e\)-v\(c\)"), g(r"v\(e\)-v\(b\)"))
        except AttributeError:
            pass
    return res


def main():
    out = []
    pr = lambda *a: (print(*a), out.append(" ".join(str(x) for x in a)))
    h_typ = hfe(1.0)
    s_lo, s_hi = 220.0 / h_typ, 475.0 / h_typ
    pr("model hFE(-5V,-2mA,25C) = %.1f; BF scale for hFE 220 / 475: %.3f / %.3f" % (h_typ, s_lo, s_hi))
    pr("hFE check: lo %.0f hi %.0f; at 85 C typ %.0f, at -20 C typ %.0f" %
       (hfe(s_lo), hfe(s_hi), hfe(1.0, 85), hfe(1.0, -20)))
    counts = list(range(2000, 3701, 4))
    # 1. YOLO ceiling + pinch-off, PNP-limited (Imax 95 mA = chip upper bound, so the PNP sets the current)
    pr("\n1. Ic (mA) vs ELRS count, PAOUT1 sink Imax 95 mA (PNP-limited)")
    pr("Re  hFE   T   | 2000  2500  3000  3133  3263  3300  3400  3500  3700 | pinch(<0.1mA) | P_Q max mW")
    table = {}
    for re_ in (10, 15, 27, 47):
        for sc, hl in ((s_lo, 220), (s_hi, 475)):
            for t in (-20, 25, 85):
                r = dc_sweep(re_, sc, t, 0.095, counts)
                table[(re_, hl, t)] = r
                ic = {c: r[c][0] * 1e3 for c in r}
                pinch = min((c for c in counts if ic[c] < 0.1), default=None)
                pq = max(r[c][0] * r[c][2] for c in r) * 1e3
                near = lambda k: ic[min(ic, key=lambda c: abs(c - k))]
                pr("%2d  %3d %4d  | %s | %s | %.0f" % (re_, hl, t, " ".join("%5.1f" % near(k) for k in
                   (2000, 2500, 3000, 3133, 3263, 3300, 3400, 3500, 3700)), pinch, pq))
    # 2. steps per 6 dB (I^2 law: P ~ Idc^2) at a given 25 mW current I25 -> count(I25) - count(2*I25), /4.096
    pr("\n2. real duty steps (0.1 %% each) between I25 and 2*I25 (6 dB, Pout ~ Idc^2), 25 C, PNP-limited")
    pr("Re  hFE | I25=0.5mA  1mA   2mA   4mA   8mA")
    for re_ in (10, 15, 27, 47):
        for hl in (220, 475):
            r = table[(re_, hl, 25)]
            ic = sorted(((c, r[c][0]) for c in counts), key=lambda x: x[0])

            def cnt_at(i):  # highest count where Ic >= i (Ic falls with count)
                cc = [c for c, x in ic if x >= i]
                return max(cc) if cc else None
            row = []
            for i25 in (0.5e-3, 1e-3, 2e-3, 4e-3, 8e-3):
                a, b = cnt_at(i25), cnt_at(2 * i25)
                row.append("%5s" % ("%.0f" % ((a - b) * 1000 / 4096) if a and b else "-"))
            pr("%2d  %3d | %s" % (re_, hl, "  ".join(row)))
    # 3. PAOUT1-limited case: sink wants only 10 mA -> PNP saturates at YOLO; check Vce, base current, PAOUT1 V
    pr("\n3. PAOUT1 sink Imax 10 mA (stage wants less than the PNP ceiling): YOLO count 2000")
    for re_ in (10, 47):
        for sc, hl in ((s_lo, 220), (s_hi, 475)):
            r = dc_sweep(re_, sc, 25, 0.010, [2000, 3000])
            pr("Re %2d hFE %3d: count 2000 Ie %.1f mA V(PAOUT1) %.2f V Vec %.2f V; count 3000 Ie %.1f mA V(PAOUT1) %.2f V"
               % (re_, hl, r[2000][0] * 1e3, r[2000][1], r[2000][2], r[3000][0] * 1e3, r[3000][1]))
    # 4. reset / boot (GPIO13 undriven) and HD mode
    pr("\n4. GPIO13 undriven at reset (Imax 95 mA, 25 C)")
    for re_ in (10, 47):
        for sc, hl in ((s_lo, 220), (s_hi, 475)):
            for rpull, lab in (("1G", "floating (1 GOhm)"), ("45k", "45 kOhm pull-down")):
                m, name = model_bf(sc)
                net = "\n".join(["* reset", m, ".temp 25", STAGE.format(vdd=VDD, re=re_, q=name, imax=0.095, cfx="1u"),
                                 "RPD pwm 0 %s" % rpull, ".control", "op", "print -i(VDD) v(b)", ".endc", ".end"])
                o = run(net)
                i = float(re.findall(r"-i\(vdd\) = ([-0-9.eE+]+)", o)[-1])
                pr("Re %2d hFE %3d %-18s: Ic %.2f mA" % (re_, hl, lab, i * 1e3))
    pr("\n5. HD mode: +3V3_VTX = 0 V, GPIO13 high 3.3 V, RTC6705 unpowered (PAOUT1 0 V)")
    for sc, hl in ((s_lo, 220), (s_hi, 475)):
        for t in (25, 85):
            m, name = model_bf(sc)
            net = "\n".join(["* hd", m, ".temp %g" % t,
                             STAGE.format(vdd=0, re=10, q=name, imax=0.0, cfx="1u").replace(
                                 "BLOAD pa 0 I = 0.0*tanh(v(pa)/0.25)", "RPA pa 0 1k"),
                             "VPWM pwm 0 3.3", ".control", "op", "print i(VPWM)", "print (-i(VDD))", "print v(e)-v(b)", "print v(c)-v(b)", ".endc", ".end"])
            o = run(net)
            ip = float(re.findall(r"i\(vpwm\) = ([-0-9.eE+]+)", o)[-1])
            ir = float(re.findall(r"\(-i\(vdd\)\) = ([-0-9.eE+]+)", o)[-1])
            veb = float(re.findall(r"v\(e\)-v\(b\) = ([-0-9.eE+]+)", o)[-1])
            vcb = float(re.findall(r"v\(c\)-v\(b\) = ([-0-9.eE+]+)", o)[-1])
            pr("hFE %3d %2d C: GPIO13 current %.2e A, into the rail %.2e A, Veb %.2f V (VEBO -5 V), Vcb %.2f V"
               % (hl, t, -ip, ir, veb, vcb))
    # 6. ripple: transient 10 kHz PWM at 3133 counts (about the 100 mW calibration point), Re 10, typ hFE
    pr("\n6. 10 kHz PWM ripple at count 3133 (76.4 %), Re 10, hFE typ, C124/C125 at 0.6 uF (DC bias)")
    m, name = model_bf(1.0)
    d = (3133 * 1000 // 4096) / 1000.0
    net = "\n".join(["* ripple", m, ".temp 25", STAGE.format(vdd=VDD, re=10, q=name, imax=0.095, cfx="0.6u"),
                     "VPWM pwm 0 PULSE(0 3.3 0 10n 10n %gu 100u)" % (100 * d - 0.02),
                     ".tran 1u 200m 150m 1u", ".control", "run",
                     "meas tran ibmin MIN i(VDD) from=150m to=200m", "meas tran ibmax MAX i(VDD) from=150m to=200m",
                     "meas tran vbmin MIN v(b) from=150m to=200m", "meas tran vbmax MAX v(b) from=150m to=200m",
                     ".endc", ".end"])
    o = run(net)
    g = lambda k: float(re.findall(k + r"\s*=\s*([-0-9.eE+]+)", o)[-1])
    imax, imin = -g("ibmin"), -g("ibmax")
    pr("Ic %.2f..%.2f mA (ripple %.2f %% p-p), base %.4f..%.4f V (%.2f mV p-p)" %
       (imin * 1e3, imax * 1e3, 100 * (imax - imin) / ((imax + imin) / 2), g("vbmin"), g("vbmax"),
        1e3 * (g("vbmax") - g("vbmin"))))
    # step response (averaged PWM): pit 3700 -> 3133, 99 % settling of Ic
    fn = os.path.join(HERE, "_step.dat")
    net = "\n".join(["* step", m, ".temp 25", STAGE.format(vdd=VDD, re=10, q=name, imax=0.095, cfx="0.6u"),
                     "VPWM pwm 0 PWL(0 %g 1m %g 1.0001m %g)" % (3.3 * 0.903, 3.3 * 0.903, 3.3 * d),
                     ".tran 10u 60m 0 10u", ".control", "run", "wrdata %s (-i(VDD))" % fn, ".endc", ".end"])
    run(net)
    rows = [tuple(float(x) for x in l.split()[:2]) for l in open(fn) if l.strip()]
    os.unlink(fn)
    fin = rows[-1][1]
    t99 = max(t for t, i in rows if abs(i - fin) > 0.01 * fin)
    pr("averaged step pit (3700) -> 3133: final %.2f mA, within 1 %% after %.1f ms" % (fin * 1e3, (t99 - 1e-3) * 1e3))
    open(os.path.join(HERE, "pnp_spice.out.txt"), "w").write("\n".join(out) + "\n")


if __name__ == "__main__":
    main()

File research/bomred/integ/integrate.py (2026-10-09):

#!/usr/bin/env python3
"""Integrate the four BOM-reduction tracks: apply the confirmed proposals to bom_plan.json and recount
BOM placements, unique MPN lines and area per side (floorplan sides, fpinfo land extents).
Area metrics: 'halo' = land extent + 0.1 mm per side (FLOORPLAN.md 'occupied incl. 0.1 mm halo'),
'pkg' = land extent only (FLOORPLAN.md 'package area')."""
import copy
import itertools
import json
import sys

REPO = "/home/user/OpenAIO-Whoop/hardware"
FPI = "/tmp/claude-0/-home-user/84218be5-e7e2-573d-8ce2-dce426a96e71/scratchpad/p23/fp/work/fpinfo.json"
bp = json.load(open(f"{REPO}/bom_plan.json"))
fpl = {p["ref"]: p for p in json.load(open(f"{REPO}/floorplan.json"))["parts"]}
fi = json.load(open(FPI))

F0201 = "lib:C_0201_0603Metric_W"
F0402 = "lib:C_0402_1005Metric_W"
FDFN3 = "lib:DFN-3L_L1.0-W0.6-P0.65-BR_W"   # AP1606 land; BC857BM (SOT883) reuses it (vtx track V2 note 2)
EXT = {"PICO_7x7": (7.5, 7.5)}              # ESP32-PICO-V3 land about 7.5 mm square (rx-vtx §4)


def ext(fp):
    if fp in EXT:
        return EXT[fp]
    e = fi[fp]["ext"]
    return (e[2] - e[0], e[3] - e[1])


def area(fp, halo):
    w, h = ext(fp)
    return (w + 0.2) * (h + 0.2) if halo else w * h


def base():
    out = []
    for p in bp["parts"]:
        if p["exclude_from_bom"]:
            continue
        out.append(dict(ref=p["ref"], mpn=p["mpn"], fp=p["footprint"], side=fpl[p["ref"]]["side"],
                        block=p["block"], value=p["value"]))
    return out


class S:
    def __init__(self, parts):
        self.p = {q["ref"]: q for q in copy.deepcopy(parts)}

    def rm(self, *refs):
        for r in refs:
            assert r in self.p, r
            del self.p[r]

    def mpn(self, ref, mpn, fp=None, value=None):
        assert ref in self.p, ref
        self.p[ref]["mpn"] = mpn
        if fp:
            self.p[ref]["fp"] = fp
        if value:
            self.p[ref]["value"] = value

    def add(self, ref, mpn, fp, side, value=""):
        assert ref not in self.p, ref
        self.p[ref] = dict(ref=ref, mpn=mpn, fp=fp, side=side, block="new", value=value)

    def move(self, ref, side):
        self.p[ref]["side"] = side

    def stats(self):
        ps = list(self.p.values())
        r = dict(parts=len(ps), lines=len({q["mpn"] for q in ps}))
        for m in ("halo", "pkg"):
            for sd in "FB":
                r[f"{m}_{sd}"] = sum(area(q["fp"], m == "halo") for q in ps if q["side"] == sd)
        return r

    def copy(self):
        n = S([])
        n.p = copy.deepcopy(self.p)
        return n


def corrected(s):
    """Corrected baseline: D24/D34 spec parts not yet in bom_plan + ESP32 CAP1 (PS-00)."""
    s.add("C_VIN1", "GRM155C81A225KE11D", F0402, "B", "2.2uF")     # D24 TPS2116 VIN1
    s.add("R_HYS", "RC0201FR-071M5L", F0201, "B", "1.5M")           # D34 hysteresis
    s.add("C_ENF", "GRM033R61E104KE14D", F0201, "B", "100nF")       # D34 EN filter
    s.add("C_CAP1", "GRM033R61A103KA01J", F0201, "B", "10nF")       # ESP32 CAP1 (Espressif: required)
    s.mpn("R9", "RC0201FR-0790K9L", value="90.9k")                   # D34 value


# ---------------- proposals (functions mutate a state) ----------------
def BR_RV4(s):   # ESP32-PICO-V3 SiP
    s.rm("U17", "C81", "X2", "C71", "C72", "C80", "C74", "C75", "C77", "C78", "C79")
    if "C_CAP1" in s.p:
        s.rm("C_CAP1")
    s.mpn("U16", "ESP32-PICO-V3", fp="PICO_7x7")


def BR_FALLBACK_RX(s):   # no RV-4: PS-09 (C77); CAP1 stays; U17 relocation is placement only
    s.rm("C77")


def BR_PE7(s):
    s.rm("C18", "C24", "C36")


def BR_V2(s):
    s.rm("Q27", "R71", "R72", "R73", "R74", "R75", "R76", "R77", "C124", "C125")
    s.add("Q27n", "BC857BM,315", FDFN3, "F")
    s.add("R71n", "RC0201FR-071KL", F0201, "F")
    s.add("R72n", "RC0201FR-071KL", F0201, "F")
    s.add("C124n", "GRM033R61A105ME44D", F0201, "F")
    s.add("C125n", "GRM033R61A105ME44D", F0201, "F")
    s.add("R75n", "RC0201FR-0710RL", F0201, "F")     # Re 10-15 ohm per verification; 10R = R65 line


def BR_PS12(s):  # fallback drive stage values (fixes F-A)
    s.rm("R73")
    for r in ("R71", "R72", "R74"):
        s.mpn(r, "RC0201FR-073K3L", value="3.3k")
    for c in ("C124", "C125"):
        s.mpn(c, "GRM033R61A105ME44D", value="1uF")
    s.mpn("R75", "RC0201FR-0775RL", value="75R")


def BR_V1(s):
    s.rm("R78", "R79", "R83")
    s.mpn("Q28", "AP1606", fp=FDFN3)


def BR_F1(s):
    s.rm("U23", "C126", "C127")


def BR_PS05(s):
    s.rm("C3", "C4")


def BR_PS08(s):
    s.rm("C90", "C93")


def BR_F2(s):
    s.rm("C55", "C53")


def BR_GYRO(s):
    s.rm("C63", "C64")


def BR_V3(s):
    s.rm("C99")


def BR_V4(s):
    s.rm("C97")


def BR_V5(s):
    s.rm("C119")


def BR_PE1(s):
    s.rm("Q1")


def BR_PE3(s):
    s.rm("R6")


def BR_PS11(s):
    s.rm("R69")


def BR_PS07(s):
    s.rm("C69")
    s.move("C70", "B")


def BR_PS18(s):
    s.rm("C120")
    s.mpn("C13", "GRM155C80J106ME11D", fp=F0402, value="10uF")


def BR_RV1(s):
    s.mpn("U18", "SX1281IMLTRT")


def BR_PS01(s):
    for q in s.p.values():
        if q["mpn"] == "GRM033R61E104KE14D":
            q["mpn"] = "GRM033C81E104KE14D"


def BR_PS02(s):
    for q in s.p.values():
        if q["mpn"] in ("GRM033R61A103KA01J", "GRM033R71C103KA01D"):
            q["mpn"] = "GRM033R71A103KA01D"


def BR_PS03(s):
    for r in ("C18", "C24", "C30", "C36", "C_VIN1"):
        if r in s.p:
            s.mpn(r, "GRM155C80J106ME11D", value="10uF")


def BR_PS17(s):
    s.mpn("R41", "RC0201FR-0727RL", value="27R")


def BR_PS19(s):
    s.mpn("C123", "CL05A475MP5NRNC", fp=F0402, value="4.7uF")


# resistor value options (verified alternatives only)
def r11(s, v):
    if v == "3.3k":
        s.mpn("R11", "RC0201FR-073K3L", value="3.3k")      # PS-16
    elif v == "2.4k":
        s.mpn("R11", "RTT012401FTH", value="2.4k")         # PE-10


def pr1(s, v):
    if v == "3.3k/1.2k":                                   # PS-14
        s.mpn("R7", "RC0201FR-073K3L", value="3.3k")
        s.mpn("R8", "RC0201FR-071K2L", value="1.2k")
    elif v == "49.9k/18k":                                 # PE-12 PR1
        s.mpn("R7", "RC0201FR-0749K9L", value="49.9k")
        s.mpn("R8", "RC0201FR-0718KL", value="18k")


def o4en(s, v):
    if v == "PS-15":
        s.mpn("R9", "RC0201FR-0733KL", value="33k")
        s.mpn("R10", "RC0201FR-0718KL", value="18k")
        s.mpn("R_HYS", "RC0201FR-07510KL", value="510k")


def fb(s, v):
    if v == "47k/6.2k":                                    # PS-13 = PE-12 FB
        s.mpn("R4", "RC0201FR-0747KL", value="47k")
        s.mpn("R5", "RC0201FR-076K2L", value="6.2k")
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

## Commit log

2026-08-11 docs: ask contributors to raise proposals in Discord first
    CONTRIBUTING.md now points at the Discord server and asks contributors to tag
    the developers before opening an issue or starting work, so proposals get
    checked against work in progress, board locks and committed production runs.
2026-08-13 Reset to the planned shape: a specification, not a half-drawn design
    The repo claimed more than it had. The KiCad project was sheets imported from the sibling repos. Its board carried 360 footprints, 784 tracks and 134 zones, byte-identical to OpenAIO, which two different products cannot be.
    A planned repo is three files plus research. README.md is now the
    specification: what we want built, why, the requirements, prior art in the
    line, and the open questions that have to be answered before anything gets
    drawn. Answering those needs no KiCad and is where this repo needs help.
    The component and market research is kept, moved to research/, because that is
    exactly what a planned repo should ac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
    [OpenAIO-Whoop.kicad_pcb, OpenAIO-Whoop.kicad_sch, blackbox.kicad_sch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]
2026-08-13 Reset to the planned shape: a specification, not a half-drawn design (#9)
    exactly what a planned repo shou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
    [OpenAIO-Whoop.kicad_pcb, OpenAIO-Whoop.kicad_sch, blackbox.kicad_sch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]
2026-08-15 README: planned-stage shape from the template
    Same content as the planned reset, reordered into the line-wide sections:
    badge row, Why, target Specifications, Constraints, Prior art, Open questions.
2026-08-26 docs: rescope to a 1S AIO with an onboard analog VTX
    OpenAIO now covers 2-6S, so 1S-2S digital-only left this board with no range
    of its own and no reason to exist next to it. Rescoped to 1S with an onboard
    analog VTX, which is the one thing a 2-6S digital-capable AIO cannot serve.
    Adds a "Blocked on the VTX" section: RTC6705 has no LCSC listing, so the VTX
    cannot be assembled at JLCPCB today and the board waits on that part or a
    sourceable equivalent. Power stage stays an open question rather than the
    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
2026-09-19 docs: closing documentation package
    AGENTS.md 7 to 64 lines: drops the link to a workspace path absent from a public clone, states what exists (submodule only, no KiCad project), Repo and Environment, the template Rules section stamped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
    Claude-Session: https://claude.ai/code/session_012HzaDQJftK4deuM7TyZ3Cv
2026-09-24 docs: stop hard-coding JLCPCB as the assembly house (#3)
    README named JLCPCB as the default assembly house in the VTX-dependency
    note, the Specifications table, and Constraints. production/ release
    manifests for recent boards (OpenFC-Lite-Mini, OpenFC-Lite,
    OpenESC-20x20/30x30, the OpenRX family) all ship as PCBGoGo handoff/order
    packages, not JLCPCB. This repo has no hardware/ design yet (only the pinned
    KiCad-Library submodule), so there is no JLCPCB-specific export to point to
    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
2026-10-06 tools: headless KiCad 10 agent environment setup script
    Installs kicad-cli and pcbnew from the kicad-10.0-releases PPA, plus a
    venv with kicad-skip, kicad-python and easyeda2kicad. Adds the PPA by
    hand because add-apt-repository fails when python3 is not the distro
    Python.
    Claude-Session: https://claude.ai/code/session_01RFaS5jnC9tnPam9GBgmGnG
2026-10-06 hardware: KiCad project scaffold from hardware-template
    Empty OpenAIO-Whoop project with the line-standard board setup, library
    tables, and a board-setup check script (layers, stackup, rules, presets,
    net classes, outline, holes; --spec compares against expected values).
    AGENTS.md Environment now carries the template commands plus the Linux
    toolchain. ERC is clean; DRC reports only the missing outline, which is
    drawn once the spec fixes it.
    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
    [OpenAIO-Whoop.kicad_pcb, OpenAIO-Whoop.kicad_sch]
2026-10-06 tools: headless stackup setter and custom-rule parse check
    apply_stackup.py sets the physical stackup through pcbnew and kicad-skip
    (KiCad 10's IPC API can read but not write it). check_rules.py fails
    when KiCad cannot parse the .kicad_dru, which kicad-cli drc otherwise
    ignores silently.
    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
    [apply_stackup.py, check_rules.py]
2026-10-06 research: lineup conventions and checker; title blocks to rev1
    LINEUP-CONVENTIONS.md records the OpenDrone schematic, silkscreen,
    project and docs conventions with evidence from the brand repo and the
    shipped boards. check_conventions.py checks the machine-checkable rules;
    it passes OpenFC-Lite with no failures. Title blocks move to the line's
    rev1 scheme and the fabrication-toolkit options name the archive.
    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
    [OpenAIO-Whoop.kicad_pcb, OpenAIO-Whoop.kicad_sch]
2026-10-06 tools: headless schematic-to-board pipeline scripts (spike)
    sch_build.py writes schematic content from OpenDrone symbols, sync_pcb.py
    builds or updates the board from the netlist with symbol paths for
    schematic parity, pcb_build.py and freeroute.py place and route, and
    pipeline_selftest.py runs the whole chain on a toy board outside the repo.
    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
2026-10-07 wip: P0 revision round 1 and P1 board setup in progress
    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
    [OpenAIO-Whoop.kicad_pcb]
2026-10-07 hardware: P1 board setup (outline, stackup, rules, net classes, keepouts)
    setup_board.py rebuilds the board, project and rule files from the spec
    and is idempotent. 26.4 mm body with a R5.8 front corner and three ears
    on a 25.75 mm square, 6-layer 1.0 mm stackup with impedance control
    (RF 0.105 mm for 50 ohm from a field solve), 0.35/0.20 vias filled and
    capped, coloured net classes, component classes, 25 named board rules on
    top of the canonical DRU block, named keepouts, and the 16 DRC checks the
    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
    [OpenAIO-Whoop.kicad_pcb]
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2026-10-07 research: P0 consolidated with D12-D22; floorplan preview image
    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
    [OpenAIO-Whoop.kicad_pcb]
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2026-10-07 wip: P0 fix round 1 (FET pinout, decisions applied)
    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
2026-10-09 hardware: P3 library merged (symbols, footprints, 3D, datasheet-checked)
    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
    [MotorPad_1.0x1.8mm_PTH0.5.json]
2026-10-09 hardware: P2 floorplan run 2 (326/329 placed, 0 spacing, 0 DRC)
    Every BOM part placed on its planned side and region with real library
    footprints at the 0.2 mm body rule; pad labels, incutec logo and product
    name on silk. Compaction with via-in-pad follows.
    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
    [OpenAIO-Whoop.kicad_pcb]
2026-10-09 hardware: P2 floorplan compaction pass (via-in-pad counted, empty patches closed)
    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
    [OpenAIO-Whoop.kicad_pcb]
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2026-10-09 library + bom_plan: v3 parts merged (AGM210MAP, BM04B USB + SGM40661 + TPD2EUSB30, 2450AT07A0100 antenna, PY25Q128HA 3x3 NOR, PicoBlade plug-ready motor lands, SKUBAAE010 shared boot button, via test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
    [MotorPad_PicoBlade_1x03_P1.25mm_PTH0.5.json]
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2026-10-09 schematic: P4 contract, root sheet and empty sub-sheets (10 sheets, 268 refs mapped)
    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
    [OpenAIO-Whoop.kicad_sch, blackbox.kicad_sch, esc_channel.kicad_sch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]
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2026-10-09 wip: schematic sheets in progress (led)
    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
    [led.kicad_sch]
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2026-10-09 wip: schematic sheets in progress
    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
    [led.kicad_sch]
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2026-10-09 schematic: power and imu sheets drawn (ERC 0 on each sheet; P4-1/2/3/7/9/12/17/19 closed in block notes)
    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
    [power.kicad_sch]
2026-10-09 schematic: rx (ESP32-PICO-V3 + SX1281 + Wi-Fi antenna + boot button), blackbox and osd sheets drawn
    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
    [osd.kicad_sch, pads.kicad_sch, vtx.kicad_sch]
2026-10-09 schematic: vtx sheet (RTC6705 + PNP drive verified in ngspice + SE5004L + LP5907/LP5912, 58 refs) and led sheet
    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
    [vtx.kicad_sch]
2026-10-09 wip: schematic integration in progress (saved after container restart)
    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
    [OpenAIO-Whoop.kicad_sch, blackbox.kicad_sch, esc_channel.kicad_sch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]
2026-10-09 schematic: integrated (ERC 0 errors / 2 justified warnings; check_netlist 7/7; conventions 0 FAIL; visual 0 hits; 268/268 refs match bom_plan; FC+RX pin maps match PINMAP)
    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
    [OpenAIO-Whoop.kicad_pcb, OpenAIO-Whoop.kicad_sch, blackbox.kicad_sch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]
2026-10-10 wip: schematic review fixes and floorplan build in progress
    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
2026-10-10 hardware: floorplan v3 placed (272 footprints, Matrix-informed; DRC 0 errors, spacing 0; D72 mating zones + reserved via sites; D75 block outlines, function labels, RF paths; compaction: no empty pat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
    [OpenAIO-Whoop.kicad_pcb]
2026-10-10 hardware: floorplan v3 review pass (RX RF corner blocker fixed; majors listed in FLOORPLAN.md Open)
    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
    [OpenAIO-Whoop.kicad_pcb, OpenAIO-Whoop.kicad_sch, blackbox.kicad_sch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]
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2026-10-10 hardware: schematic synced to the board (271 parts, 263 nets, parity 0 errors; SPI net patterns fixed in the DRU; X1 3225 placed)
    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
    [OpenAIO-Whoop.kicad_pcb]
2026-10-10 wip: routing prep (zones and via fields) and schematic review round 4
    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
    [OpenAIO-Whoop.kicad_pcb, OpenAIO-Whoop.kicad_sch, esc_channel.kicad_sch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]
2026-10-10 schematic: review complete (4 rounds; U20 pin 1 to GND, footprint filters fixed, TPS22810DRVR, R54 270R); ERC 0 errors, check_netlist 7/7; D85-D87
    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
    [OpenAIO-Whoop.kicad_pcb, OpenAIO-Whoop.kicad_sch, esc_channel.kicad_sch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]
2026-10-10 hardware: routing loop 1 (re-synced to the final schematic; DRC 0 errors, parity 0, 262 unconnected; 355 vias, 531 mm track)
    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
    [OpenAIO-Whoop.kicad_pcb]
2026-10-10 wip: routing loop 1 final (259 unconnected, DRC 0, parity 0)
    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
    [OpenAIO-Whoop.kicad_pcb]
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2026-10-10 wip: routing loop 2 promoted (251 unconnected, DRC 0, parity 0)
    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
    [OpenAIO-Whoop.kicad_pcb]
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2026-10-10 wip: v4 prep in progress (D89 UART pad removal, D93 3D model fixes, Wi-Fi antenna research)
    Snapshot of running workflows; final numbers follow when each verifies.
    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
    [OpenAIO-Whoop.kicad_pcb, OpenAIO-Whoop.kicad_sch, pads.kicad_sch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]
2026-10-10 wip: v4 prep in progress (schematic IO trim, 3D models, footprint variants)
    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
    [power.kicad_sch, rp2350a.kicad_sch]
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2026-10-10 research: Wi-Fi antenna (D90): keep the 1.0 x 0.5 mm Johanson, partial void next to the ESP32 feed; review corrections appended
    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
2026-10-10 D89 UART pad group removed (schematic, PINMAP, IO-SET, bom_plan; ERC 0, netlist checks 7/7) and D93 3D models fixed (J32, U3, U24, U10, U14, U16, D1, U2, PicoBlade 53047-0310 on the motor lands)
    Both changes independently verified; DRC unchanged by the model edits.
    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
    [OpenAIO-Whoop.kicad_pcb]
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2026-10-10 revert D97 rules: HDI was not approved (owner question misread); through vias only stay; HDI rule set kept for comparison copies
    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
    [setup_board.py]
2026-10-10 decisions: D98 0201 confirmed (in-house PCBA), D99 oscillator if RP2350 XIN check passes, microvia test points, stack reorder via the HDI EQ
    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
2026-10-10 D100: RP2350 external 12 MHz oscillator check passed (applied at the pin-map freeze); OSCILLATOR-O3.md with review corrections
    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
2026-10-10 decisions: D105 constructive placement order (fixed frame -> ICs with GPIO map -> passives at pins -> compaction -> shrink)
    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
2026-10-10 D109 least-density footprints verified: 12 IC + 13 passive _L footprints (EFM8 EP through vias removed, RP2354A heel restored, values fixed); ~91 mm2 courtyard saved
    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
2026-10-10 WIP final schematic (D111/D113): GPIO map, D100 oscillator, final footprints, lineup power-net names; mid-run snapshot, not yet verified (ERC/netlist/DRU regen pending)
    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
2026-10-10 Final schematic (D111/D113): .kicad_pro component class refresh, SCHEMATIC.md and LIBRARY.md D111 sections; editor checks ERC 0 errors, check_netlist 7/0, conventions planned 0 FAIL; independent veri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
2026-10-10 WIP schematic verify (D113): verifier fixes in pads/vtx sheets, contract, BOM plan and docs; not yet final
    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
2026-10-10 Schematic fixes: RP2350 UART net names match the hardware UARTs (UART1 on GPIO8/9 = CRSF to the ESP32, UART0 on GPIO16/17 = TX1/RX1 pads); VTX_PWR_CTL on ESP32 GPIO4 (reset pull-down) gets R68 10k pu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
2026-10-10 Schematic fix verify: PINMAP reset-state rows for RADIO_NSS/RST, RP2350 datasheet table citations for the repo PDF build, IO-SET O4 row; fix2 independently verified (netlist: 4 UART renames + R68 10k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
2026-10-10 Schematic readability pass done (graphics only, netlist byte-identical; ERC 0 errors, check_netlist 7/0, independently reviewed); overview MCU block text 12 MHz OSC (D100)
    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
2026-10-11 Final layout fixes (WIP, verify running): RF nets single-sided (Wi-Fi match to the back with U16/AE2, C110 to the front with the VTX chain), off-board silk texts removed, 2 more pad labels placed, re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
2026-10-11 Hand-off verified in a clean clone: ERC 0 errors, DRC 0 errors / parity 0 with the repo files (with and without zone refill), all footprints and 3D models resolve; renders of the final board (4f845ba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
2026-10-11 Trim BOM to strictly needed parts, fill sourcing fields, fix library datasheets
    Owner review 2026-10-11, schematic only (board not resynced).
    Removed (17 parts): D1 TVS (clamps above every IC abs max), R2/R3/C5
    INA186 input RC, U5 TPS22810 O4 switch with C16/C129/R9/R10/R87/D2
    (VHD pad now on +5V_BST, as Matrix HD boards; HD_EN still holds the
    analog VTX off via Q28, R11 kept), R67 selector (PA_VCC is +BATT),
    TH1/R70 PA NTC and R84 (patched-ELRS only; GPIO37/GPIO4 no-connect),
    C92 and C121 (beyond SX1281 / LP5912 datasheet decoupling).
    Changed: D4 WS2812 VDD to +5V (3.5 V min); X3 TCXO pin 1 floating per
    the YXC sheet; C122/C123/C134 4.7 uF 0402 -> 0201 GRM035R60J475ME15D.
    Sourcing: LCSC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
2026-10-11 NextPCB HDI rules, library prune, docs for the minimal BOM
    Board setup through setup_board.py (generator), values from NextPCB's
    published limits (D116): annular 0.09, via 0.35/0.15, hole to track
    0.18, PTH hole to copper 0.23, PTH hole to hole 0.30, NPTH 0.40, mask
    dam 0.09. The 104 placed buried vias re-drilled 0.20 -> 0.15 with the
    pcbnew API (drill only, nothing moved). Stackup values unchanged.
    Library: 9 footprints of parts that left the design (CSD FETs,
    ESP32-D0WD, GD25Q32, W25Q WSON-8, Nexperia logic, 0.2 mm test-point
    via, unused selector) and their 5 unused 3D models removed.
    AGENTS.md / README: power tree without D1, U5, R67; ELRS recovery
    sequence corrected; board setup row fo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
2026-10-11 Critique round fixes: X3 pin 1 NC in the symbol, bom_plan ratings and notes, README battery note
    C122/C123/C134 rating 6.3 V (GRM035R60J475ME15D); U1 and U20 nets
    follow the netlist; HD_EN is GPIO19 in R11/Q28 notes; J26 on +5V_BST.
    README: no reverse-polarity, TVS or cell cutoff, unplug after landing.
    ERC 0 errors; check_netlist 7 ok.
2026-10-11 Library: X1 land from the YSO110TR sheet, symbol default footprints, orphan specs, LIBRARY.md counts
    New lib:OSC-SMD_4P-L2.0-W1.6-BL_YXC_YSO110TR_Dense for X1 (check_footprint
    PASS); 26 lib symbols now default to the footprint the schematic places;
    9 orphan land specs and an unused 3D file removed; LIBRARY.md summary
    regenerated with the _L/_Dense/_W variant table.
    check_footprint 106/106 PASS; ERC 0 errors; check_netlist 7 ok.
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2026-10-11 Board setup ready for routing: synced to the schematic, library stackup, net classes
    - sync_pcb.py: board follows the trimmed schematic (17 footprints removed,
    C122/C123/C134 to 0201, X1 to its YSO110TR land, nets renamed); the three
    vias left by removed parts deleted. DRC schematic parity: 0 issues.
    - Stackup on NextPCB library 6L-1.0mm-0.5oz-1080 with cores 0.265 (D117).
    - Net classes: VREG_LX Power, U2_FB Analog, U10_USB_DP/DM USB; 0.30 mm
    minimum-width warning rule on +5V_BST and +5V; stale PA_NTC removed from
    the inner-layer rule.
    - board_spec.json regenerated from the board (D112 outline, D116, D117).
    Validation: ERC 0 errors / 2 warnings; check_netlist 7 ok; check_rules
    parse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
2026-10-11 Stackup: NextPCB standard 6L HDI 06101H03-1080 at 1.0 mm (D117)
    1+4+1 on NextPCB's own HDI stack: 1080 0.077 / 1080 0.077 / core 0.568 /
    1080 0.077 / 1080 0.077. Each inner layer 0.077 from its GND plane, inner
    layers 0.568 apart; outer 50 ohm geometry unchanged. Standard stack, 0.20
    USD per board under the former customer-specified one at 1000 pcs.
    ERC 0 errors; check_netlist 7 ok; check_rules parsed; board_spec 31/31;
    setup_board --check up to date; DRC unchanged.
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2026-10-11 DRU: disallow through vias (D107, D116)
    Every via is a laser microvia L1-L2 / L5-L6 or a buried L2-L5 via; a
    through via placed with KiCad's V is now a DRC error. Generated by
    setup_board.py; check_rules parsed, DRC unchanged (no through vias on
    the board), board_spec 31/31.
2026-10-11 5 V input: two Schottky diodes replace the TPS2116 mux and the SGM40661 (D118)
    D9 VBUS -> +5V and D10 +5V_BST -> +5V, MSKSEMI MS2A40LDF DFN1610-2
    (LCSC C7380000, imported with import_part.py; land spec PASS). U3, R7,
    R8, U24, C131 removed; C128 is +5V bulk; PWR_FLAG on +5V. Board synced.
    Stale schematic notes rewritten (O4 switch block now "HD_EN PULL-DOWN",
    TVS, INA186 input RC, PA NTC, R67, GPIO4 control, root power table).
    ERC 0 errors; check_netlist 7 ok; sch_integrate --check clean;
    setup_board --check up to date; board_spec 31/31; sync dry run 0 changes;
    DRC unchanged.
2026-10-11 index on review/schematic-bom-trim: 1f33208 5 V input: two Schottky diodes replace the TPS2116 mux and the SGM40661 (D118)

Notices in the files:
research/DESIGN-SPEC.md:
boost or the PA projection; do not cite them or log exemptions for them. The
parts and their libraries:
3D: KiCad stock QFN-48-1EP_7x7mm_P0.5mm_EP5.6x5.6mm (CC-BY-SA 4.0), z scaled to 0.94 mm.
